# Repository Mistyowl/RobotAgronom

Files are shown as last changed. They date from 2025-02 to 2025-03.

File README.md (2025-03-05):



 

# RobotAgronom - Автор Горбачев Савелий
RobotAgronom - надёжный помощник в агрономии! 🌱
- Спроектирован в Fusion 360, напечатан на Raise 3D Pro2
- Управляется через телефон при помощи Веб-сервера

## Что умеет наш робот:
#### 1. Автоматическое перемещение
- **Калибровка скорости:** Робот учится точно рассчитывать расстояние, двигаясь 10 секунд вперед. После этого вы указываете, сколько метров он проехал, и он записывает свою скорость в энергонезависимую память. Таким образом настройки не пропадают после выключения и перезагрузки устройства.
- **Миссии:** Задайте общее расстояние (например, 100 метров) и количество остановок (например, 5). Робот равномерно распределит точки замеров почвы датчиком и будет двигаться между ними автономно.
#### 2. Работа с датчиком почвы
На каждой остановке робот:
1. Опускает датчик в почву.
2. Измеряет 9 параметров:
    - Влажность, температуру, pH
    - Уровень азота (N), фосфора (P), калия (K)
    - Электропроводность, солёность, общее количество растворённых веществ (TDS).
3. Поднимает датчик и продолжает движение.
#### 3. Сохранение и просмотр данных
- Все данные записываются на SD-карту в формате JSON. (ниже можно посмотреть структуру файла)
- В реальном времени показания отображаются в веб-интерфейсе. (появится в апдейте)
- Файлы можно извлечь и проанализировать на компьютере.
#### 4. Безопасность
- **Экстренная остановка:** В любой момент нажмите кнопку «Стоп» в интерфейсе.
- **Защита от ошибок:** Робот не запустит новую миссию, пока не завершит текущую.

## Структура файла JSON (data.json)
```
[
  {
    "timestamp": 51262,
    "humi": 22.7,
    "temp": 21.9,
    "cond": 182,
    "phph": 5.3,
    "nitro": 0,
    "phos": 45,
    "pota": 37,
    "soli": 100,
    "tds": 91
  },
  {
    "timestamp": 69584,
    "humi": 22.7,
    "temp": 21.9,
    "cond": 182,
    "phph": 5.3,
    "nitro": 0,
    "phos": 45,
    "pota": 37,
    "soli": 100,
    "tds": 91
  }
]
```

## Компонентная база
| № | Наименование детали | Кол-во | Итоговая стоимость |
| - | --- | --- | ---: |
| 1. | Контроллер ESP32 38PIN | 1 шт. | 545 ₽ |
| 2. | Шаговый двигатель 28BYJ-48 с драйвером ULN2003 | 1 шт. | 291 ₽ |
| 3. | Мотор редуктор JGY370 55 об/мин вал 6mm | 2 шт. | 1800 ₽ |
| 4. | Драйвер для двигателя L298N | 1 шт. | 320 ₽ |
| 5. | Конвертер RS485 UART (TTL) | 1 шт. | 259 ₽ |
| 6. | RS485 Modbus почвенный датчик 7 в 1 | 1 шт. | 2958 ₽ |
| 7. | Модуль кард-ридер MINI SD Arduino | 1 шт. | 205 ₽ |
| 8. | Подшипники АВЕС-7 608 RS | 1 шт. | 283 ₽ |
| 9. | Зубчатый разомкнутый ремень GT2 10мм, армированный полимерным волокном | 4 шт. | 1260 ₽ |
| 10. | Резиновое уплотнительное кольцо (внешний диаметр 12мм, толщина 2мм) | 100 шт. | 400 ₽ |
| 11. | Корпус аккумулятора 18650 | 2 шт. | 306 ₽ |
| 12. | PETG пластик используемый для печати | 3 кг. | 5700 ₽ |
| 13. | SD Card 16 гб | 1 шт. | 350 ₽ |
| 14. | Аккумулятор Li-ion 18650 | 3 шт. | 720 ₽ |
| 15. | Преобразователь напряжения LM2596 | 1 шт. | 142 ₽ |
| | | Итого: | 15 539 ₽ |

| Болты | Кол-во |
| ----- | -----: |
| M4x20 | 7 шт. |
| M8x60 | 2 шт. |
| M8x70 | 2 шт. |
| M3x30 | 20 шт. |
| Гайки | Кол-во |
| M3 | 16 шт. |
| M4 | 5 шт. |
| M8 | 6 шт. |

## Инструкция
#### Шаг 1. Подключение
1. Включите робота.
2. На телефоне/ноутбуке подключитесь к Wi-Fi:
    - **Сеть:** ```RobotControl```
    - **Пароль:** ```12345678```
3. Откройте браузер и перейдите по адресу: ```http://192.168.4.1```
#### Шаг 2. Калибровка скорости
1. Нажмите на кнопку **«Калибровочный заезд»**.
2. Робот поедет 10 секунд. Измерьте рулеткой, сколько метров он проехал.
3. Введите это значение в метрах в поле **«Реальное расстояние»** и нажмите **«Установить калибровку»**.
4. Теперь робот знает свою точную скорость.
#### Шаг 3. Запуск миссии
1. В разделе **«Программа миссии»** укажите:
    - **Общая дистанция** (например, 100 метров).
    - **Количество замеров** (например, 5 остановок).
2. Нажмите **«Старт миссии»**.
3. Робот начнёт движение. В каждой точке остановки он:
    - Остановится.
    - Опустит датчик.
    - Сделает замеры показаний и запишет их на sd-карту.
    - Поднимет датчик и поедет дальше.
#### Шаг 4. Просмотр данных
1. В веб-интерфейсе вы увидите:
    - Текущие показания датчиков.
    - Время последнего обновления.
    - Статус SD-карты.
2. Чтобы получить данные с датчика:
    - Извлеките SD-карту из робота.
    - Вставьте её в компьютер — файл ```data.json``` содержит все замеры.

## Веб-интерфейс
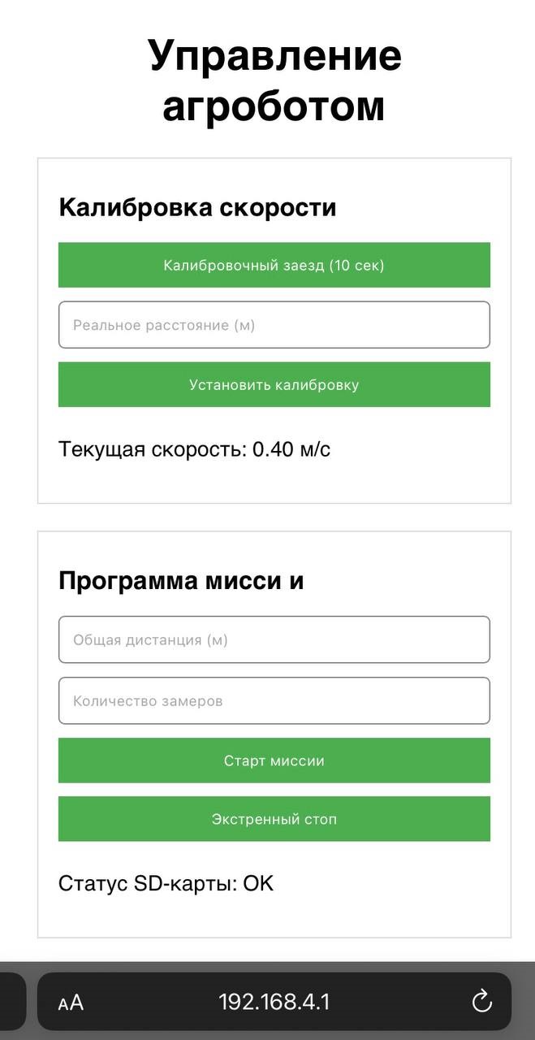
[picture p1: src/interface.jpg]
Веб-интерфейс


## Схема подключения
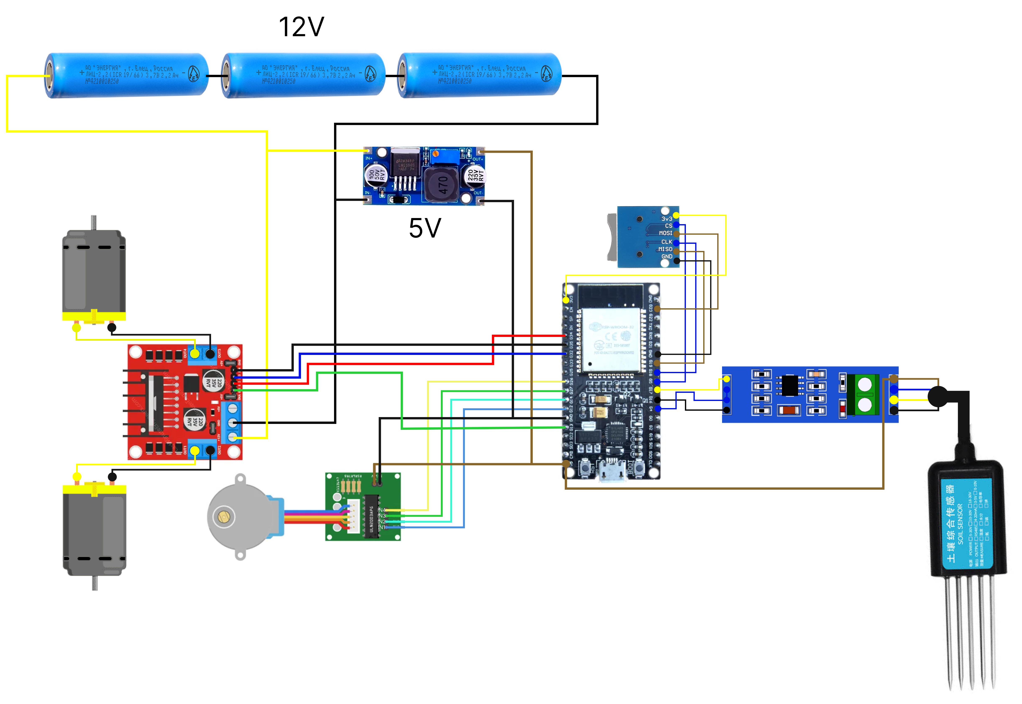
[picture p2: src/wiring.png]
Схема подключения


## Советы и устранение неполадок
- **SD-карта не определяется:**
    - Проверьте, подключена ли карта.
    - Убедитесь, что до конца вставлена карта.
    - Убедитесь, что она отформатирована в FAT32.
- **Робот не двигается:**
    - Проверьте уровень заряда батареи.
    - Убедитесь, что моторы подключены правильно.
- **Нет данных в интерфейсе:**
    - Обновите страницу (F5).
    - Убедитесь, что датчик опускается полностью.

## Обновления
* v1.0 - релиз
* v1.1 - исправлены пины подключения двигателей, добавлена схема распиновки + минорные изменения
* v1.2 - обновлен README.md, добавлена компонентная база

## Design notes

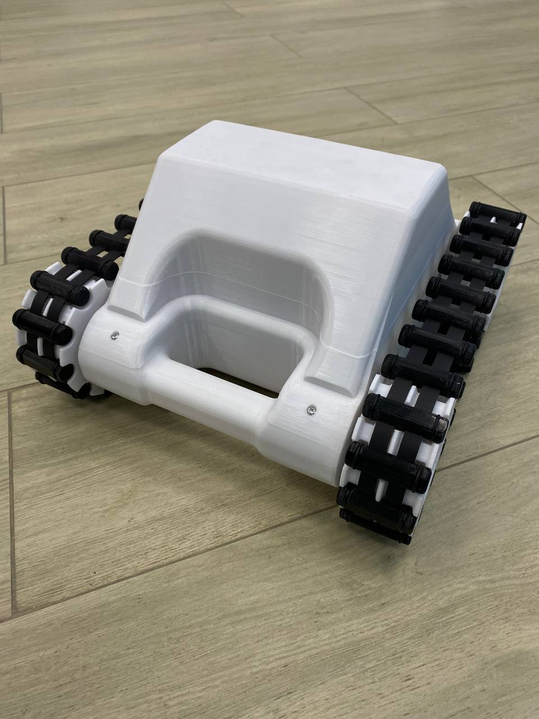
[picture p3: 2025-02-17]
photo/Сзади.jpg

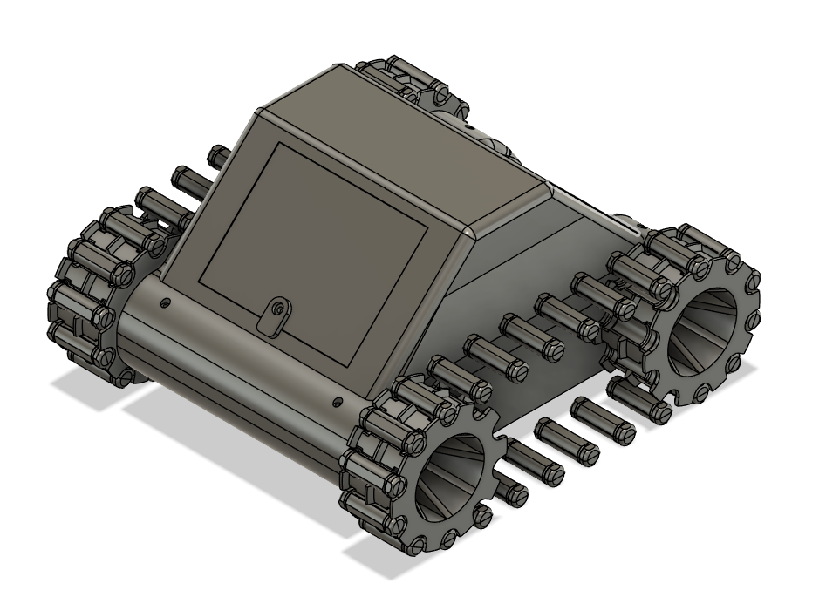
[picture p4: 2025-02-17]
photo/ОбщийПлан_2.png

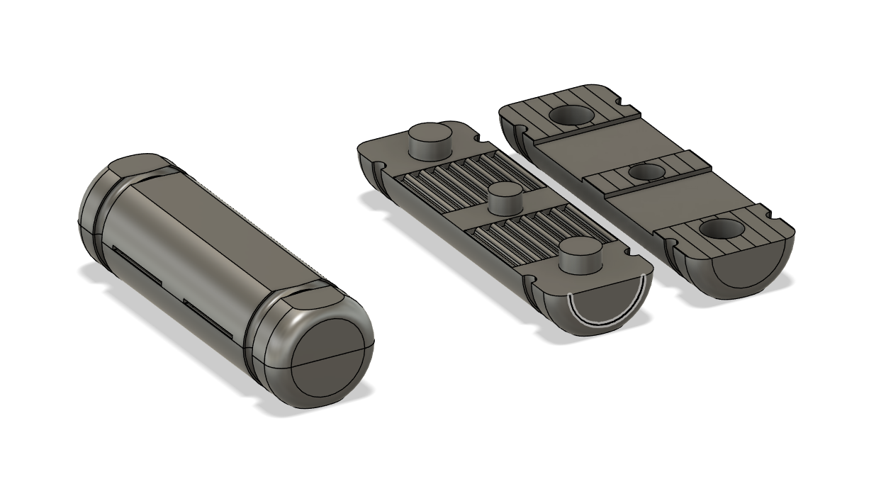
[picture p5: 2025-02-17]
photo/Секция_Гесенецы.png

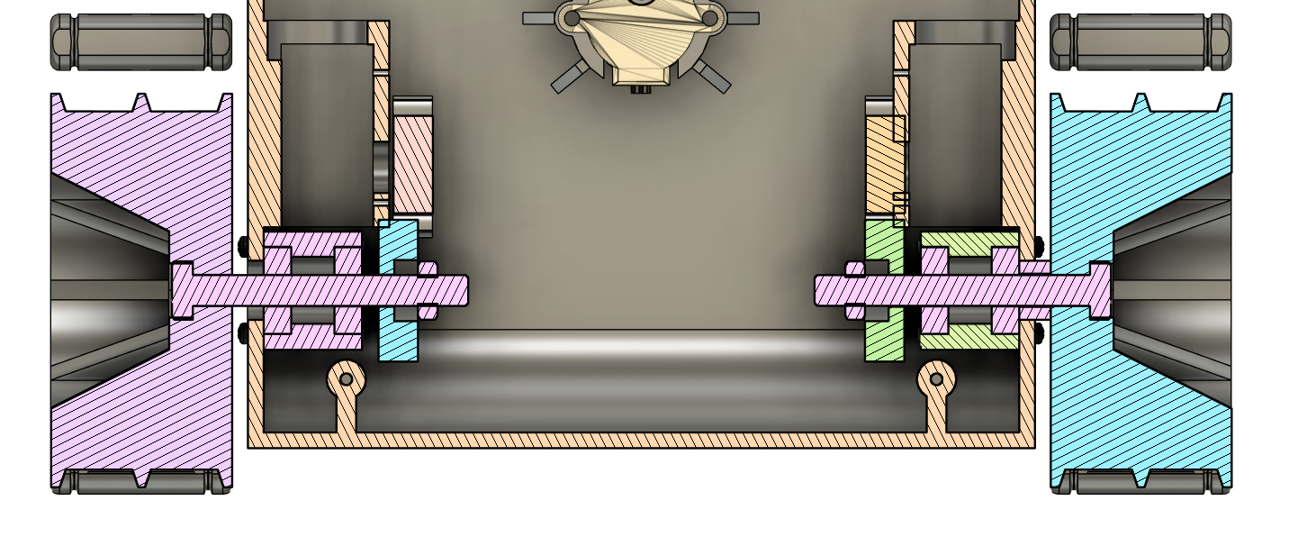
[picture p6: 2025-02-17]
photo/Срез_Ходовая часть.png

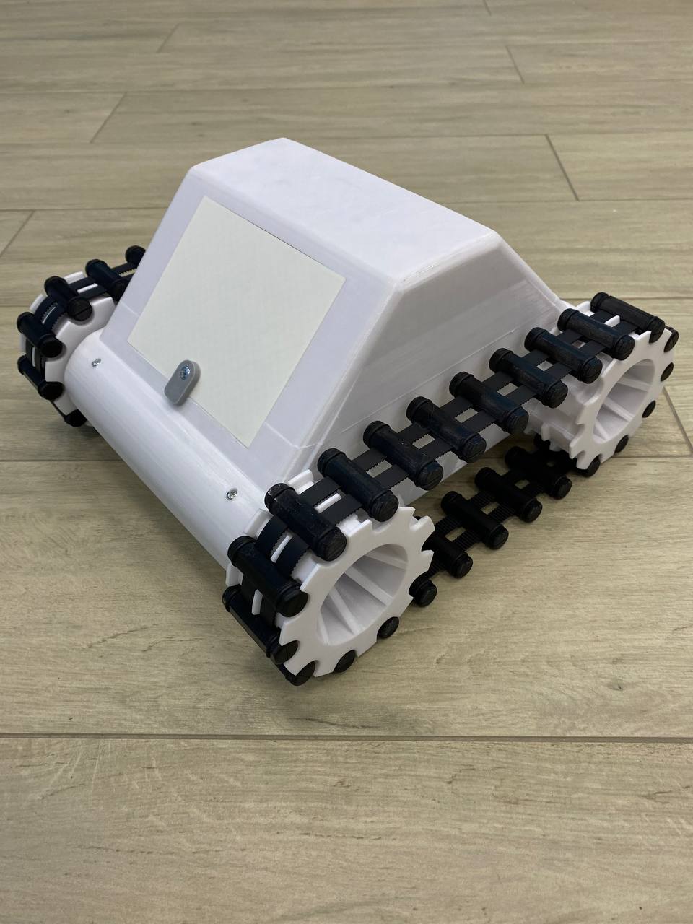
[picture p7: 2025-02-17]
photo/Спереди.jpg

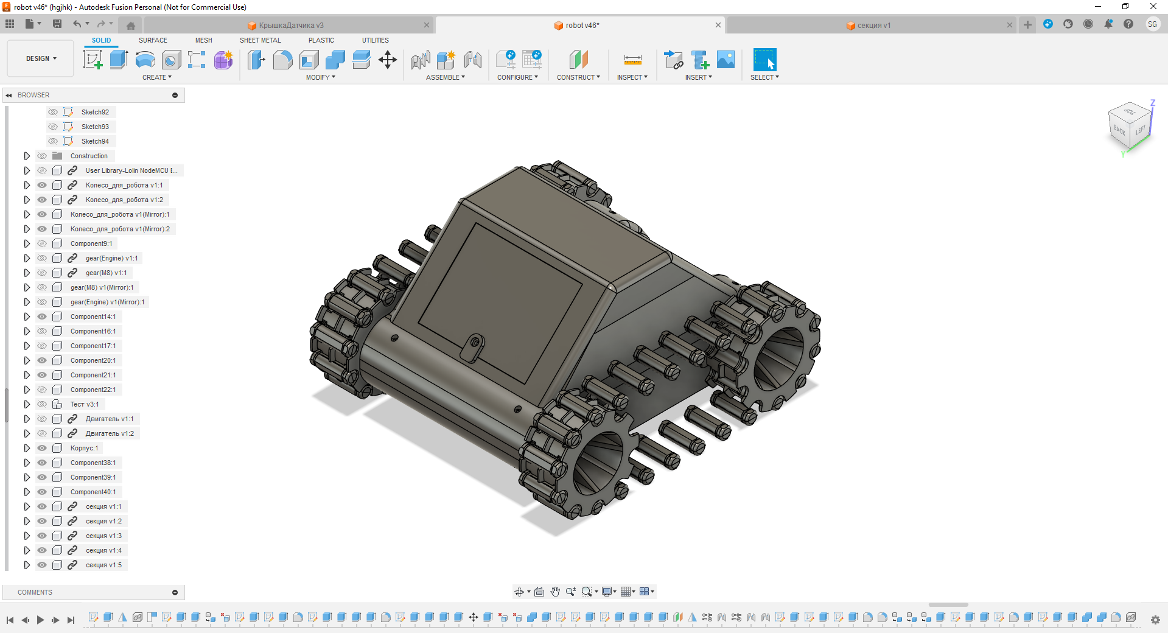
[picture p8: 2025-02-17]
photo/ПроцессРаботы.png

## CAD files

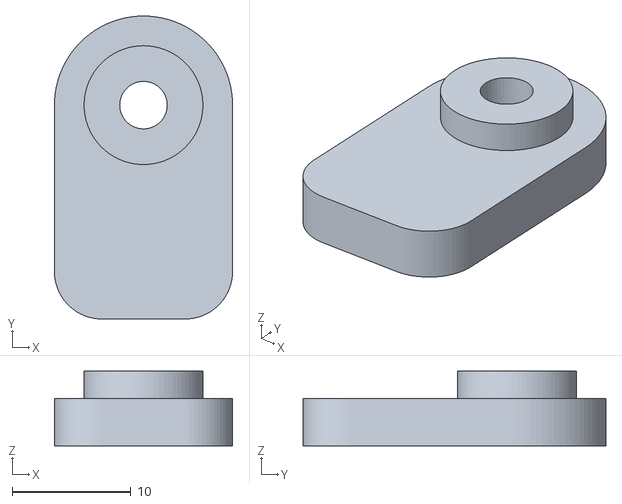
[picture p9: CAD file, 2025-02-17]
model/Locker_part2.stl
15.0 x 25.5 x 6.30

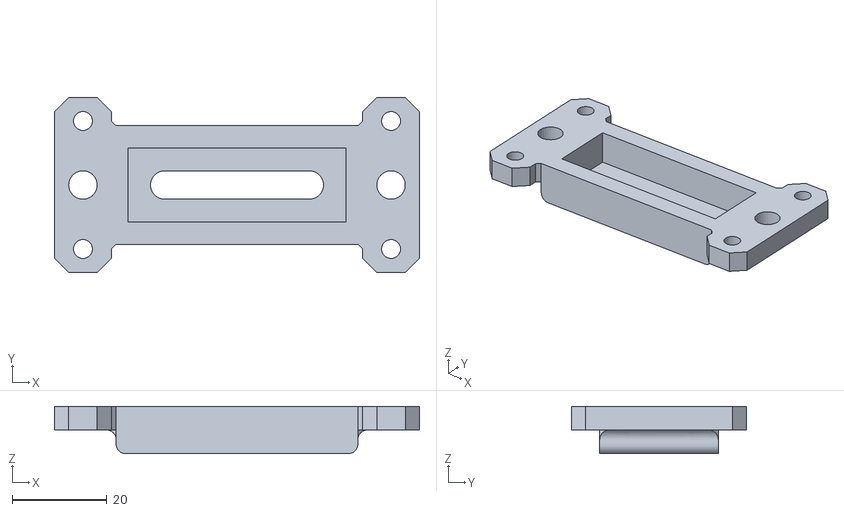
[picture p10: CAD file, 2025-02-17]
model/CapForSensor_Part1.stl
77.0 x 37.0 x 10.0

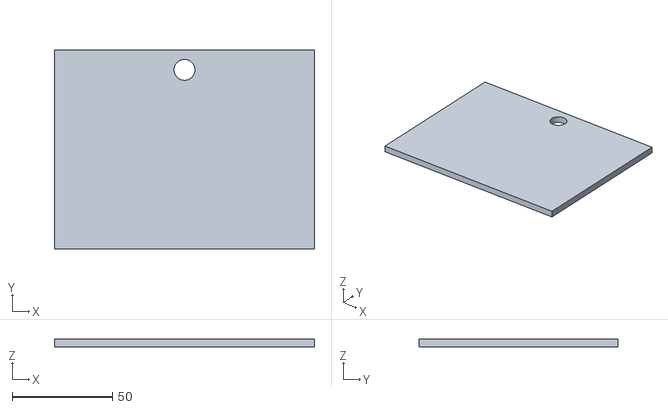
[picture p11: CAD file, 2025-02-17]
model/Manhole.stl
129.4 x 99.2 x 4.00

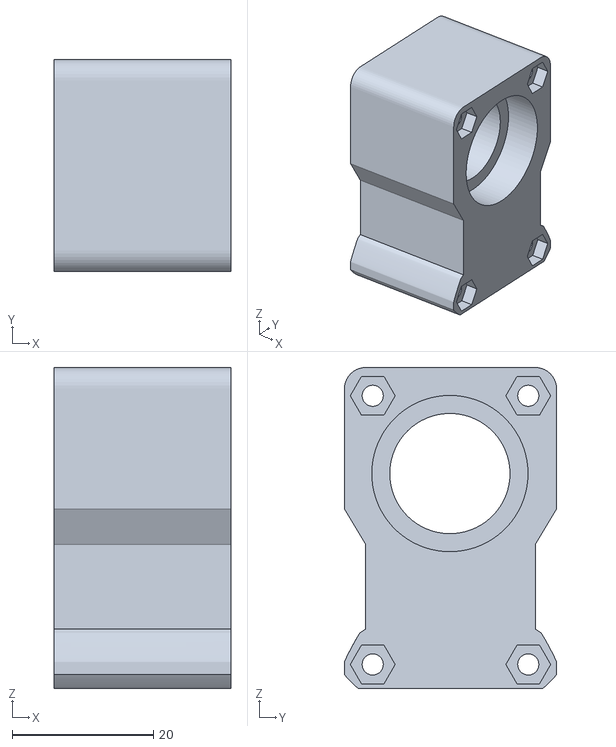
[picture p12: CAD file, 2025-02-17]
model/For_bearings.stl
25.0 x 30.0 x 45.4

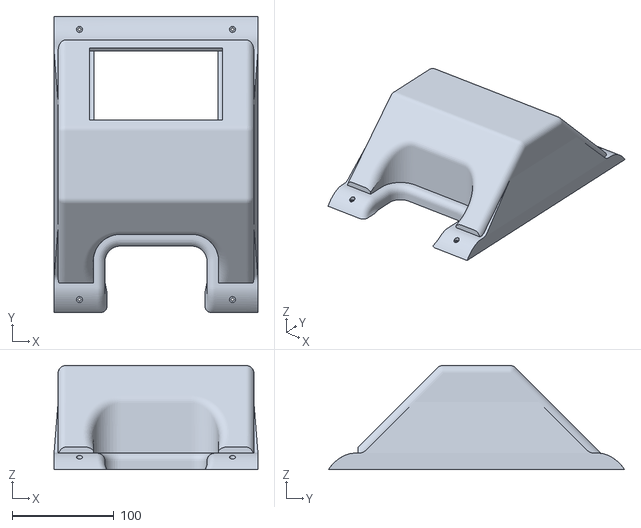
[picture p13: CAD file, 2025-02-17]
model/Lid.stl
200.0 x 290.4 x 102.0

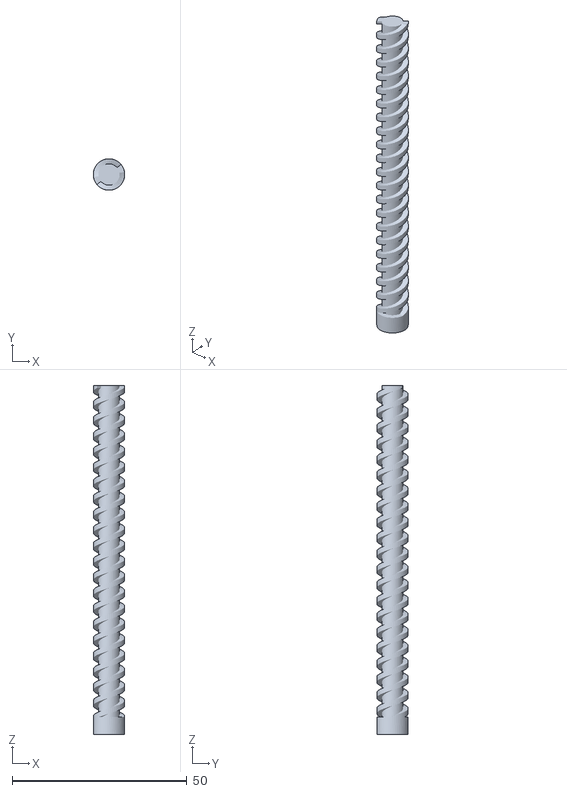
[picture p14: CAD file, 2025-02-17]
model/Thread.stl
9.00 x 9.00 x 100.0

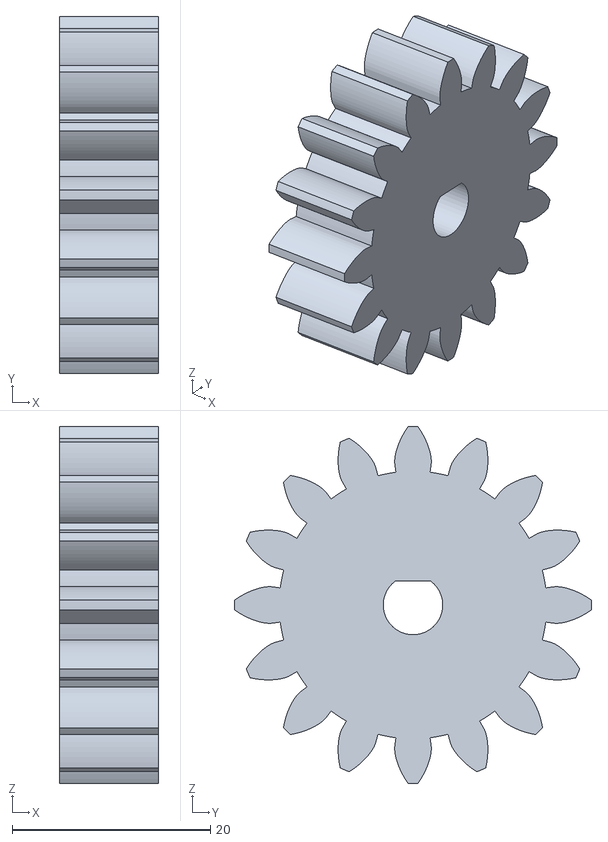
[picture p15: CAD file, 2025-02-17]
model/Gear(Engine).stl
10.0 x 36.0 x 36.0

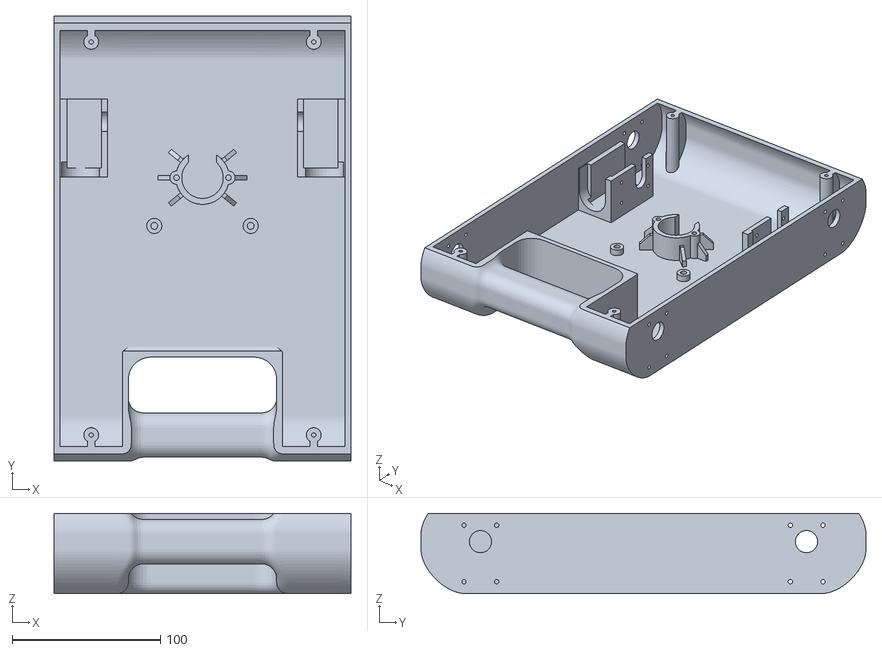
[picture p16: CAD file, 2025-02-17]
model/Body.stl
200.0 x 300.0 x 54.0

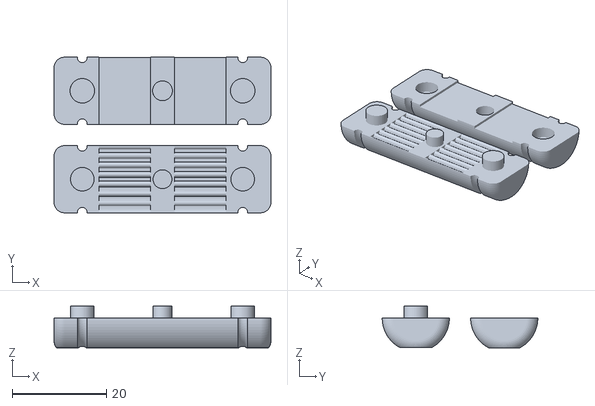
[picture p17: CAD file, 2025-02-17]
model/Section.stl
46.0 x 33.0 x 8.81

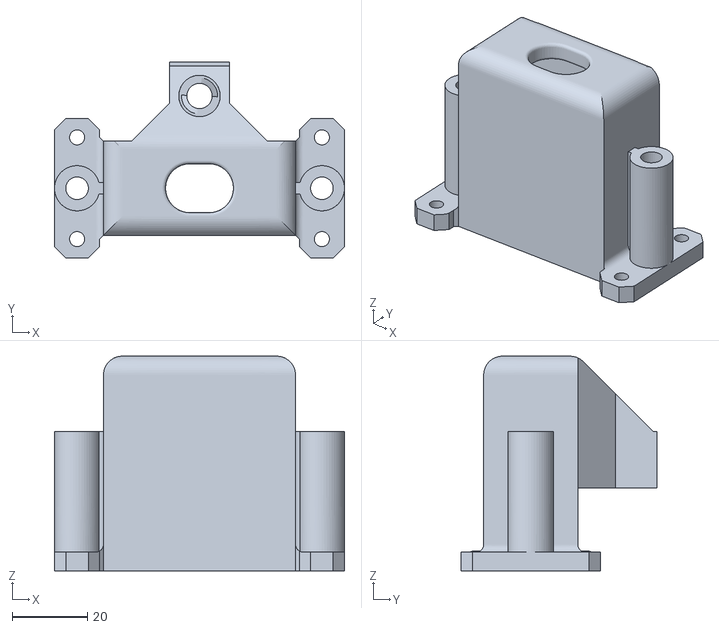
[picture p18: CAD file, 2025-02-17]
model/CapForSensor_Part2.stl
77.0 x 52.0 x 57.0

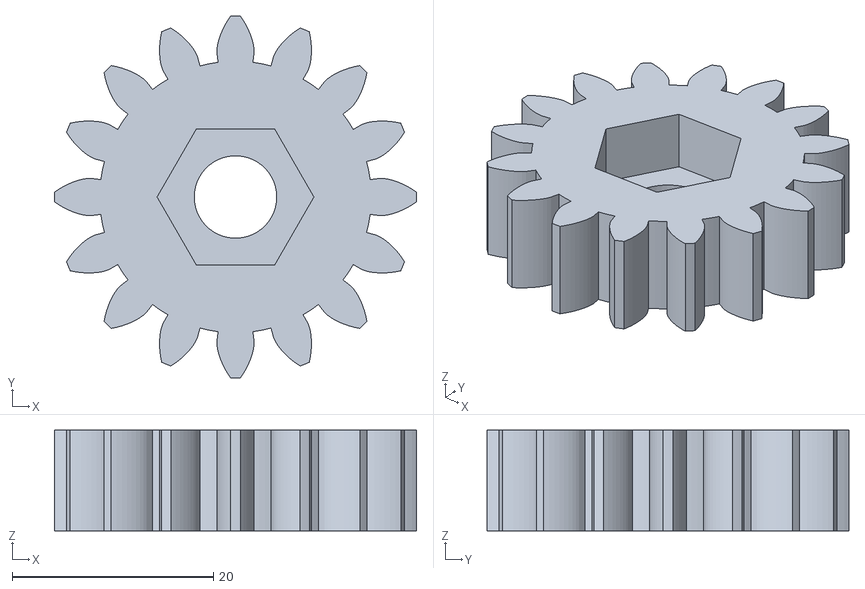
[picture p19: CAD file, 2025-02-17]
model/Gear(M8).stl
36.0 x 36.0 x 10.0

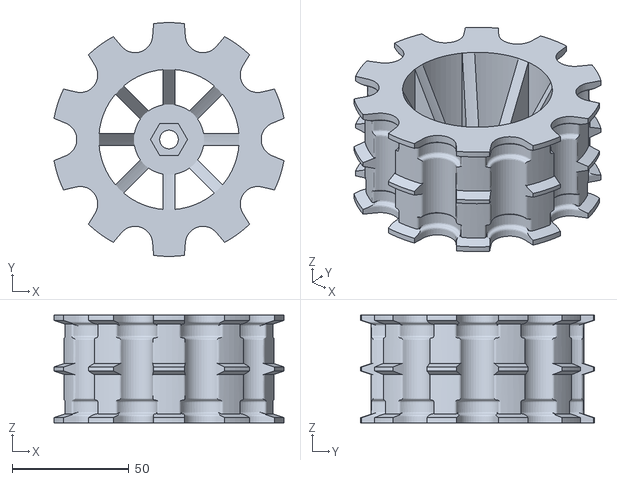
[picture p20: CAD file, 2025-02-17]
model/Wheel.stl
98.3 x 100.0 x 46.0

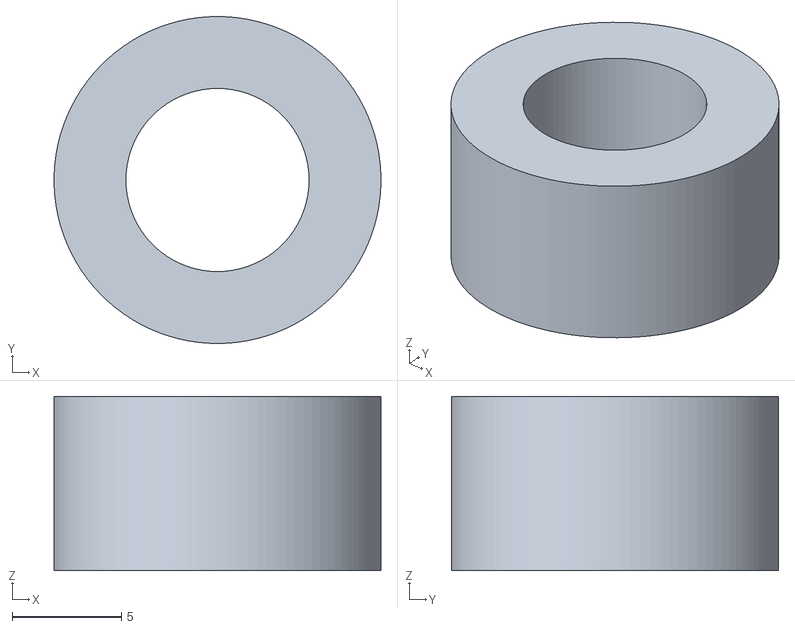
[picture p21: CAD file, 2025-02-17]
model/Remote_washer_8mm.stl
15.0 x 15.0 x 8.00

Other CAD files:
model/Locker_part1.stl

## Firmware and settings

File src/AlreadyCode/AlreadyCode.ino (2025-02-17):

#include <WiFi.h>
#include <WebServer.h>
#include <Preferences.h>
#include <GyverStepper.h>
#include <ArduinoJson.h>
#include "FS.h"
#include "SD.h"
#include "SPI.h"

// Настройка IP адреса
IPAddress local_ip(192,168,4,1);
IPAddress gateway(192,168,4,1);
IPAddress subnet(255,255,255,0);

Preferences prefs;
WebServer server(80);

// Конфигурация шагового двигателя
GStepper<STEPPER4WIRE> stepper(2038, 26, 14, 27, 12);

// Конфигурация DC моторов
#define MOTOR_A_IN1 13
#define MOTOR_A_IN2 34
#define MOTOR_B_IN3 32
#define MOTOR_B_IN4 35

// Подключение SD-карты
#define SD_MISO 19
#define SD_MOSI 23
#define SD_SCK 18
#define SD_CS 05

// Подключение Soil Sensor датчика 7 in 1
#define RE 4 
#define RXD2 17
#define TXD2 16
// Адресы регисторов чтения
const byte humi[] = { 0x01, 0x03, 0x00, 0x00, 0x00, 0x01, 0xe84, 0x0a }; // Влажность
const byte temp[] = { 0x01, 0x03, 0x00, 0x01, 0x00, 0x01, 0xd5, 0xca }; // Температура
const byte cond[] = { 0x01, 0x03, 0x00, 0x02, 0x00, 0x01, 0x25, 0xca }; // Электропроводность
const byte phph[] = { 0x01, 0x03, 0x00, 0x03, 0x00, 0x01, 0x74, 0x0a }; // Водородный показатель
const byte nitro[] = { 0x01, 0x03, 0x00, 0x04, 0x00, 0x01, 0xec5, 0xcb }; // Азот
const byte phos[] = { 0x01, 0x03, 0x00, 0x05, 0x00, 0x01, 0xe94, 0x0b }; // Фосфор
const byte pota[] = { 0x01, 0x03, 0x00, 0x06, 0x00, 0x01, 0xe64, 0x0b }; // Калий
const byte sali[] = { 0x01, 0x03, 0x00, 0x07, 0x00, 0x01, 0xe35, 0xcb };  // Соленость
const byte tds[] = { 0x01, 0x03, 0x00, 0x08, 0x00, 0x01, 0xe05, 0xc8 }; // Общее количество растворенных твердых веществ
byte values[11]; // Переменная для хранения значения NPK

// Состояния системы
enum OperationState {
  IDLE,
  CALIBRATING,
  MOVING,
  LOWERING_PROBE,
  MEASURING,
  RAISING_PROBE
};

// Глобальные переменные
OperationState currentState = IDLE;
float calibratedSpeed = 0.5; // м/с
unsigned long movementEndTime = 0;
const float calibrationTime = 10.0; // секунд
bool sdInitialized = false; // SD-карта

// Параметры миссии
float totalDistance = 0;
int measurementsCount = 0;
int currentMeasurement = 0;
float segmentDistance = 0;

void setup() {
  Serial.begin(115200);

  // Датчик
  Serial1.begin(4800, SERIAL_8N1, RXD2, TXD2);
  pinMode(RE, OUTPUT);
  digitalWrite(RE, LOW);
  
  // Настройка выводов
  pinMode(MOTOR_A_IN1, OUTPUT);
  pinMode(MOTOR_A_IN2, OUTPUT);
  pinMode(MOTOR_B_IN3, OUTPUT);
  pinMode(MOTOR_B_IN4, OUTPUT);

  stepper.setRunMode(KEEP_SPEED);
  // можно установить скорость
  stepper.setSpeed(500);    // в шагах/сек
  // режим следования к целевй позиции
  stepper.setRunMode(FOLLOW_POS);
  // можно установить позицию
  stepper.setTarget(-2024);    // в шагах
  // установка макс. скорости в градусах/сек
  // stepper.setMaxSpeedDeg(400);
  
  // установка макс. скорости в шагах/сек
  stepper.setMaxSpeed(500);
  // установка ускорения в шагах/сек/сек
  stepper.setAcceleration(300);
  // отключать мотор при достижении цели
  stepper.autoPower(true);
  // включить мотор (если указан пин en)
  stepper.enable();
  
  // Загрузка калибровки
  prefs.begin("robot-data");
  calibratedSpeed = prefs.getFloat("speed", 0.5);
  prefs.end();

  // Настройка Wi-Fi
  WiFi.softAP("RobotControl", "12345678");
  
  // Маршруты веб-сервера
  server.on("/", handleRoot);
  server.on("/start-calibration", handleStartCalibration);
  server.on("/set-calibration", handleSetCalibration);
  server.on("/start-mission", handleStartMission);
  server.on("/stop", handleStop);

  SPI.begin(SD_SCK, SD_MISO, SD_MOSI, SD_CS);
  if(!SD.begin(SD_CS)) {
    Serial.println("SD Card Mount Failed");
    sdInitialized = false;
  } else {
    sdInitialized = true;
    createHeader(); // Создать файл с заголовками
  }
  
  server.begin();
}

void loop() {
  server.handleClient();
  processOperations();
}

void createHeader() {
  if(sdInitialized) {
    if(!SD.exists("/data.json")) {
      File file = SD.open("/data.json", FILE_WRITE);
      if(file) {
        file.println("[]"); // Инициализируем пустой массив
        file.close();
      }
    }
  }
}

void logDataToSD(float humi, float temp, float cond, float ph, 
                float nitro, float phos, float pota, 
                float sali, float tds) {
  if(sdInitialized) {
    StaticJsonDocument<512> doc;
    
    // Заполняем данные
    doc["timestamp"] = millis();
    doc["humi"] = humi;
    doc["temp"] = temp;
    doc["cond"] = cond;
    doc["ph"] = ph;
    doc["nitro"] = nitro;
    doc["phos"] = phos;
    doc["pota"] = pota;
    doc["sali"] = sali;
    doc["tds"] = tds;

    // Открываем файл для записи
    File file = SD.open("/data.json", FILE_APPEND);
    if(file) {
      // Сериализуем JSON в компактном формате
      serializeJson(doc, file);
      file.println(); // Добавляем перевод строки
      file.close();
      Serial.println("JSON logged to SD");
    }
  }
}

void processOperations() {
  switch(currentState) {
    case CALIBRATING:
      if(millis() > movementEndTime) {
        stopMotors();
        currentState = IDLE;
      }
      break;
      
    case MOVING:
      if(millis() > movementEndTime) {
        stopMotors();
        startLoweringProbe();
      }
      break;
      
    case LOWERING_PROBE:
      if(!stepper.tick()) {
        currentState = MEASURING;
        startMeasurement();
      }
      break;
      
    case MEASURING:
      if(millis() > movementEndTime) {
        startRaisingProbe();
      }
      break;
      
    case RAISING_PROBE:
      if(!stepper.tick()) {
        currentMeasurement++;
        if(currentMeasurement < measurementsCount) {
          startNextSegment();
        } else {
          currentState = IDLE;
        }
      }
      break;
  }
}

// ================== Управление DC моторами ==================
void startMotorsForward() {
  digitalWrite(MOTOR_A_IN1, HIGH);
  digitalWrite(MOTOR_A_IN2, LOW);
  digitalWrite(MOTOR_B_IN3, HIGH);
  digitalWrite(MOTOR_B_IN4, LOW);
}

void stopMotors() {
  digitalWrite(MOTOR_A_IN1, LOW);
  digitalWrite(MOTOR_A_IN2, LOW);
  digitalWrite(MOTOR_B_IN3, LOW);
  digitalWrite(MOTOR_B_IN4, LOW);
}

// ================== Калибровка скорости ==================
void handleStartCalibration() {
  if(currentState == IDLE) {
    startMotorsForward();
    movementEndTime = millis() + (calibrationTime * 1000);
    currentState = CALIBRATING;
    server.send(200, "text/plain", "Калибровка начата! Двигайтесь 10 сек");
  }
}

void handleSetCalibration() {
  if(currentState == CALIBRATING && server.hasArg("d")) {
    float realDistance = server.arg("d").toFloat();
    calibratedSpeed = realDistance / calibrationTime;
    
    prefs.begin("robot-data");
    prefs.putFloat("speed", calibratedSpeed);
    prefs.end();
    
    currentState = IDLE;
    server.send(200, "text/plain", "Скорость: " + String(calibratedSpeed) + " м/с");
  }
}

// ================== Управление зондом ==================
void startLoweringProbe() {
  stepper.setTarget(-16000, ABSOLUTE); // Опускание на полную глубину 50000
  currentState = LOWERING_PROBE;
}

void startRaisingProbe() {
  stepper.setTarget(0, ABSOLUTE); // Подъем в исходное положение
  currentState = RAISING_PROBE;
}

void startMeasurement() {
  movementEndTime = millis() + 5000; // 5 секунд на замер
  float val_humi, val_temp, val_cond, val_phph, val_nitro, val_phos, val_pota, val_soli, val_tds;
  // ================== Влажность ==================
  Serial.print("Humidity: ");
  digitalWrite(RE, HIGH);
  delay(10);
  for (uint8_t i = 0; i < sizeof(humi); i++) Serial1.write(humi[i]);
  Serial1.flush();
  digitalWrite(RE, LOW);
  delay(100);
  for (byte i = 0; i < 7; i++) {
    values[i] = Serial1.read();
  }
  val_humi = int(values[3] << 8 | values[4]);
  val_humi = val_humi / 10;
  Serial.print(" = ");
  Serial.print(val_humi, 1);
  Serial.println(" %");
  delay(200);
  // ================== Температура ==================
  Serial.print("Temperature: ");
  digitalWrite(RE, HIGH);
  delay(10);
  for (uint8_t i = 0; i < sizeof(temp); i++) Serial1.write(temp[i]);
  Serial1.flush();
  digitalWrite(RE, LOW);
  delay(100);
  for (byte i = 0; i < 7; i++) {
    values[i] = Serial1.read();
  }
  val_temp = int(values[3] << 8 | values[4]);
  val_temp = val_temp / 10;
  Serial.print(" = ");
  Serial.print(val_cond, 1);
  Serial.println(" deg.C");
  delay(200);
  // ================== Электропроводность ==================
  Serial.print("Conductivity: ");
  digitalWrite(RE, HIGH);
  delay(10);
  for (uint8_t i = 0; i < sizeof(cond); i++) Serial1.write(cond[i]);
  Serial1.flush();
  digitalWrite(RE, LOW);
  delay(100);
  for (byte i = 0; i < 7; i++) {
    values[i] = Serial1.read();
  }
  val_cond = int(values[3] << 8 | values[4]);
  Serial.print(" = ");
  Serial.print(val_cond);
  Serial.println(" uS/cm");
  delay(200);
  // ================== Водородный показатель ==================
  Serial.print("pH: ");
  digitalWrite(RE, HIGH);
  delay(10);
  for (uint8_t i = 0; i < sizeof(phph); i++) Serial1.write(phph[i]);
  Serial1.flush();
  digitalWrite(RE, LOW);
  delay(100);
  for (byte i = 0; i < 7; i++) {
    values[i] = Serial1.read();
  }
  val_phph = int(values[3] << 8 | values[4]);
  val_phph = val_phph / 10;
  Serial.print(" = ");
  Serial.println(val_phph, 1);
  delay(200);
  // ================== Азот ==================
  Serial.print("Nitrogen: ");
  digitalWrite(RE, HIGH);
  delay(10);
  for (uint8_t i = 0; i < sizeof(nitro); i++) Serial1.write(nitro[i]);
  Serial1.flush();
  digitalWrite(RE, LOW);
  delay(100);
  for (byte i = 0; i < 7; i++) {
    values[i] = Serial1.read();
  }
  val_nitro = int(values[3] << 8 | values[4]);
  Serial.print(" = ");
  Serial.print(val_nitro);
  Serial.println(" mg/L");
  delay(200);
  // ================== Фосфор ==================
  Serial.print("Phosphorus: ");
  digitalWrite(RE, HIGH);
  delay(10);
  for (uint8_t i = 0; i < sizeof(phos); i++) Serial1.write(phos[i]);
  Serial1.flush();
  digitalWrite(RE, LOW);
  delay(100);
  for (byte i = 0; i < 7; i++) {
    values[i] = Serial1.read();
  }
  val_phos = int(values[3] << 8 | values[4]);
  Serial.print(" = ");
  Serial.print(val_phos);
  Serial.println(" mg/L");
  delay(200);
  // ================== Калий ==================
  Serial.print("Potassium: ");
  digitalWrite(RE, HIGH);
  delay(10);
  for (uint8_t i = 0; i < sizeof(pota); i++) Serial1.write(pota[i]);
  Serial1.flush();
  digitalWrite(RE, LOW);
  delay(100);
  for (byte i = 0; i < 7; i++) {
    values[i] = Serial1.read();
  }
  val_pota = int(values[3] << 8 | values[4]);
  Serial.print(" = ");
  Serial.print(val_pota);
  Serial.println(" mg/L");
  delay(200);
  // ================== Соленость ==================
  Serial.print("Salinity: ");
  digitalWrite(RE, HIGH);
  delay(10);
  for (uint8_t i = 0; i < sizeof(sali); i++) Serial1.write(sali[i]);
  Serial1.flush();
  digitalWrite(RE, LOW);
  delay(100);
  for (byte i = 0; i < 7; i++) {
    values[i] = Serial1.read();
  }
  val_soli = int(values[3] << 8 | values[4]);
  Serial.print(" = ");
  Serial.print(val_soli);
  Serial.println(" g/L");
  delay(200);
  // ================== Общее количество растворенных твердых веществ ==================
  Serial.print("TDS: ");
  digitalWrite(RE, HIGH);
  delay(10);
  for (uint8_t i = 0; i < sizeof(tds); i++) Serial1.write(tds[i]);
  Serial1.flush();
  digitalWrite(RE, LOW);
  delay(100);
  for (byte i = 0; i < 7; i++) {
    values[i] = Serial1.read();
  }
  val_tds = int(values[3] << 8 | values[4]);
  Serial.print(" = ");
  Serial.print(val_tds);
  Serial.println(" mg/L");
  delay(200);

  if(sdInitialized) {
    // Читаем существующий файл
    File file = SD.open("/data.json", FILE_READ);
    if(file) {
      // Парсим JSON массив
      DynamicJsonDocument doc(2048);
      DeserializationError error = deserializeJson(doc, file);
      file.close();

      if(!error) {
        // Добавляем новые данные
        JsonObject newEntry = doc.createNestedObject();
        newEntry["timestamp"] = millis();
        newEntry["humi"] = val_humi;
        newEntry["temp"] = val_temp;
        newEntry["cond"] = val_cond;
        newEntry["phph"] = val_phph;
        newEntry["nitro"] = val_nitro;
        newEntry["phos"] = val_phos;
        newEntry["pota"] = val_pota;
        newEntry["soli"] = val_soli;
        newEntry["tds"] = val_tds;

        // Перезаписываем файл
        file = SD.open("/data.json", FILE_WRITE);
        if(file) {
          serializeJsonPretty(doc, file); // Красивое форматирование
          file.close();
        }
      }
    }
  }

  currentState = MEASURING;
  // Здесь будет вызов вашей функции измерения
}

// ================== Логика миссии ==================
void handleStartMission() {
  if(currentState == IDLE && server.hasArg("distance") && server.hasArg("measurements")) {
    totalDistance = server.arg("distance").toFloat();
    measurementsCount = server.arg("measurements").toInt();
    
    if(measurementsCount > 0 && totalDistance > 0) {
      segmentDistance = totalDistance / measurementsCount;
      currentMeasurement = 0;
      startNextSegment();
      server.send(200, "text/plain", "Миссия начата!");
    }
  }
}

void startNextSegment() {
  unsigned long duration = (segmentDistance / calibratedSpeed) * 1000;
  startMotorsForward();
  movementEndTime = millis() + duration;
  currentState = MOVING;
}

void handleStop() {
  currentState = IDLE;
  stopMotors();
  // probeStepper.step(0); // Прервать текущее движение зонда
  stepper.stop();
  server.send(200, "text/plain", "Операция прервана");
}

// ================== Веб-интерфейс ==================
void handleRoot() {
  String html = R"rawliteral(
  <!DOCTYPE HTML>
  <html>
  <head>
    <meta name="viewport" content="width=device-width, initial-scale=1">
    <meta charset="UTF-8">
    <style>
      body {font-family: sans-serif;}
      h1 {margin: 0; text-align: center;}
      h3 {margin: 10px 0;}
      input, button {width: 100%; padding: 10px; margin: 5px 0;}
      button {background: #4CAF50; color: white; border: none;}
      input {box-sizing: border-box;}
      .container {max-width: 600px; margin: auto; padding: 20px;}
      .section {margin: 20px 0; padding: 15px; border: 1px solid #ddd;}
    </style>
    <script>
      function send(url, params) {
        fetch(url + (params || ''))
          .then(r => r.text())
          .then(t => alert(t));
      }
    </script>
  </head>
  <body>
    <div class="container">
      <h1>Управление агроботом</h1>
      
      <div class="section">
        <h3>Калибровка скорости</h3>
        <button onclick="send('/start-calibration')">Калибровочный заезд (10 сек)</button>
        <input type="number" id="calibDistance" placeholder="Реальное расстояние (м)">
        <button onclick="send('/set-calibration?d=' + document.getElementById('calibDistance').value)">
          Установить калибровку
        </button>
        <p>Текущая скорость: )rawliteral" + String(calibratedSpeed) + R"rawliteral( м/с</p>
      </div>

      <div class="section">
        <h3>Программа мисси
        и</h3>
        <input type="number" id="distance" placeholder="Общая дистанция (м)" step="0.1">
        <input type="number" id="measurements" placeholder="Количество замеров">
        <button onclick="send('/start-mission?distance=' + 
          document.getElementById('distance').value + 
          '&measurements=' + document.getElementById('measurements').value)">
          Старт миссии
        </button>
        <button onclick="send('/stop')">Экстренный стоп</button>
        <p>Статус SD-карты: )rawliteral" + (sdInitialized ? String("OK") : String("Ошибка")) + R"rawliteral(</p>
      </div>
    </div>
  </body>
  </html>
  )rawliteral";
  
  server.send(200, "text/html", html);
}

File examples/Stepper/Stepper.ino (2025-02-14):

#include <WiFi.h>
#include <WebServer.h>
#include <GyverStepper.h>
GStepper<STEPPER4WIRE> stepper(2048, 26, 14, 27, 12);
// мотор с драйвером ULN2003 подключается по порядку пинов, но крайние нужно поменять местами
// то есть у меня подключено D2-IN1, D3-IN2, D4-IN3, D5-IN4, но в программе поменял 5 и 2
// создание объекта
// steps - шагов на один оборот вала (для расчётов с градусами)
// step, dir, pin1, pin2, pin3, pin4 - любые GPIO
// en - пин отключения драйвера, любой GPIO
//GStepper<STEPPER2WIRE> stepper(steps, step, dir);                   // драйвер step-dir
//GStepper<STEPPER2WIRE> stepper(steps, step, dir, en);               // драйвер step-dir + пин enable
//GStepper<STEPPER4WIRE> stepper(steps, pin1, pin2, pin3, pin4);      // драйвер 4 пин
//GStepper<STEPPER4WIRE> stepper(steps, pin1, pin2, pin3, pin4, en);  // драйвер 4 пин + enable
//GStepper<STEPPER4WIRE_HALF> stepper(steps, pin1, pin2, pin3, pin4);     // драйвер 4 пин полушаг
//GStepper<STEPPER4WIRE_HALF> stepper(steps, pin1, pin2, pin3, pin4, en); // драйвер 4 пин полушаг + enable
const char* ssid = "RobotControl";
const char* password = "12345678";
void setup() {
  Serial.begin(115200);
  // режим поддержания скорости
  stepper.setRunMode(KEEP_SPEED);
  // можно установить скорость
  stepper.setSpeed(120);    // в шагах/сек
  stepper.setSpeedDeg(80);  // в градусах/сек
  // режим следования к целевй позиции
  stepper.setRunMode(FOLLOW_POS);
  // можно установить позицию
  stepper.setTarget(-2024);    // в шагах
  stepper.setTargetDeg(-360);  // в градусах
  // установка макс. скорости в градусах/сек
  stepper.setMaxSpeedDeg(400);
  
  // установка макс. скорости в шагах/сек
  stepper.setMaxSpeed(400);
  // установка ускорения в градусах/сек/сек
  stepper.setAccelerationDeg(300);
  // установка ускорения в шагах/сек/сек
  stepper.setAcceleration(300);
  // отключать мотор при достижении цели
  stepper.autoPower(true);
  // включить мотор (если указан пин en)
  stepper.enable();
}
void loop() {
  // просто крутим туды-сюды
  if (!stepper.tick()) {
    static bool dir;
    dir = !dir;
    stepper.setTarget(dir ? -1024 : 1024);
  }
}
